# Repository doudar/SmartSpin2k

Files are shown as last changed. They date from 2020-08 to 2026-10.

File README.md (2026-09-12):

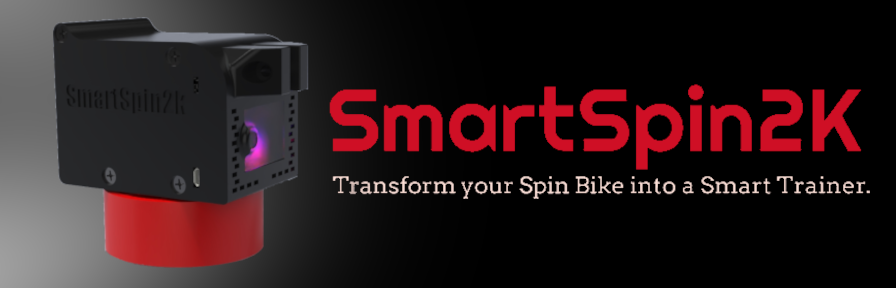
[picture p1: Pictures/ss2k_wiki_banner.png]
ss2k banner


# You can visit us at [Facebook](https://www.facebook.com/groups/716297469953492/)
# Did you know there's a SmartSpin2k companion App?

Find the source code here! -> [SS2kConfigApp](https://github.com/doudar/SS2kConfigApp/tree/develop) 

You can get it from the Apple App Store here:
<div style="display: flex; flex-wrap: wrap;">
<a href="https://apps.apple.com/us/app/smartspin2k-companion-app/id6477836948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" style="display: inline-block;">

</a>
</div>

Or for Android devices: 
<div style="display: flex; flex-wrap: wrap;">
<a href="https://play.google.com/store/apps/details?id=com.smartspin2k.app">

</a>
</div>

# About
SmartSpin2k is a DIY project that allows you to turn any spin bike into a smart trainer. With SmartSpin2k, you can connect your spin bike to Zwift, TrainerRoad, or other popular training apps. This allows you to control your bike's resistance automatically, track your performance, and compete with other riders online.

SmartSpin2k is easy to build and requires only a few simple tools. The [entire build process](https://github.com/doudar/SS2k-Hardware/blob/main/SS2kR3BuildingInstructions.pdf) can be completed in under an hour.

If you are looking for a way to turn your spin bike into a smart trainer, SmartSpin2k is the perfect solution. With its new features and improvements, SmartSpin2k rev 3 is the best version yet.

## Getting Started

To get started with SmartSpin2k, you will need the following:

* A spin bike with a resistance control knob.
* A 3D printer.
* A soldering iron and basic soldering skills.

Once you have these materials, you can follow the [these instructions](https://github.com/doudar/SS2k-Hardware/blob/main/SS2kR3BuildingInstructions.pdf) to build your own SmartSpin2k. If you'd prefer to buy a pre-assembled kit, we have them for sale at [SmartSpin2k.com](https://www.smartspin2k.com/purchase-kits) 

## Features

SmartSpin2k offers a number of features, including:

* Automatic incline resistance control: SmartSpin2k can automatically control your bike's resistance based on the resistance settings in your training app. This allows you to focus on your workout and not worry about adjusting the resistance yourself.
* SmartSpin2k ERG function is a great way to improve your cycling performance. It allows you to train at a consistent power output, which is essential for improving your speed and endurance. ERG stands for "electronic resistance control." It works by automatically adjusting the resistance on your bike based on the power output you set in your training app.
* Online competition: SmartSpin2k can connect to Zwift, TrainerRoad, and many other cycling apps allowing you to compete with other riders online. This is a great way to stay motivated and push yourself to new heights.
* Do you have a spin bike that doesn't output realistic or accurate power numbers? If so, you're not alone. Many spin bikes have inaccurate power meters that can make it difficult to track your progress and train effectively. With SmartSpin2k you can calibrate the power output of your spin bike. 

## Conclusion

SmartSpin2k is a great way to turn any spin bike into a smart trainer. With its new features and improvements, SmartSpin2k Rev 3 is the best version yet. If you are looking for a way to improve your indoor cycling experience, SmartSpin2k is the perfect solution.

### Documentation
Everything you need to know is in the [SS2K Wiki](https://github.com/doudar/SmartSpin2k/wiki)
Hardware files and build assets are in [SS2k-Hardware](https://github.com/doudar/SS2k-Hardware).

## Contributing
1. Install Microsoft Visual Code. https://code.visualstudio.com/
2. Install the **pioarduino IDE** extension (`pioarduino.pioarduino-ide`) recommended by this repository in Visual Studio Code.
3. Install Python https://www.python.org/downloads/
4. Install Pre-commit. https://pre-commit.com `py -m pip install pre-commit`
5. Follow any install warnings to add pre-commit to your path. 
6. Install pre-push git hooks: `pre-commit install --hook-type pre-push`
7. Open this project in the pioarduino IDE.

For command-line builds, use a Python virtual environment and run `python -m pip install -r requirements-ci.txt` from the repository root to install the same pinned pioarduino Core used by CI. CI uses Python 3.11. If that environment already has the upstream `platformio` package installed, uninstall it before installing pioarduino; the two packages share Python modules and command names.

pioarduino still uses `platformio.ini`, the `.platformio` tool directory, and the `pio` / `platformio` commands. Build with `pio run -e release` (classic ESP32) or `pio run -e S3release` (ESP32-S3), and run native tests with `pio test -e native`. See [AGENTS.md](AGENTS.md) for build and validation details.

## Important announcement for existing users
If you experience an issue after upgrading firmware, please follow these instructions in the Wiki. Flashing instructions are available [HERE.](https://github.com/doudar/SmartSpin2k/wiki/Loading-Software)

## Licensing
The hardware designs are licensed under the [CERN Open Hardware License Version 2 - Permissive license](https://github.com/doudar/SS2k-Hardware/blob/main/Hardware/LICENSE).
The software in this project is licensed under the [GNU GENERAL PUBLIC LICENSE Version 2, June 1991 license](LICENSE).

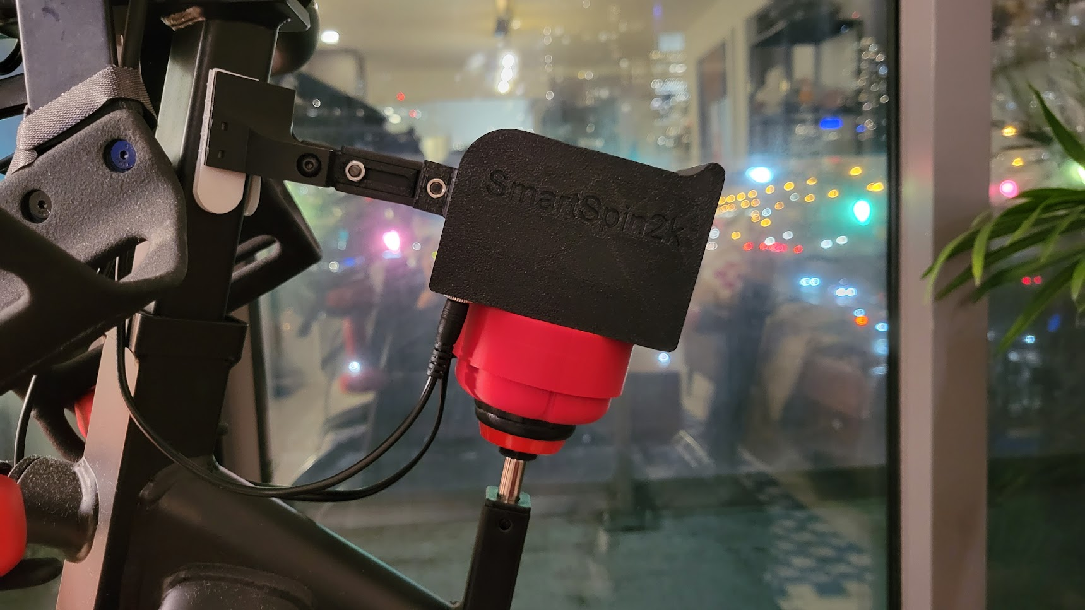
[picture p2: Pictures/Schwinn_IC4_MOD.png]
Hardware 2.0
 

[_^^@eMadman's IC4 model_](https://github.com/doudar/SS2k-Hardware/tree/main/Hardware/V2%20-%20Through%20Hole/Direct%20Mount)

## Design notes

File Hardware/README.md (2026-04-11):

# SmartSpin2k Hardware
V3 is the brand spanking new version where we've gone to a more rigid mount and designed a completly custom PCB with SMT components which can be manufactured using automated techniques. The newest PCB sports a uart->serial driver to allow direct communication with Peloton bikes. 

V2 prints easier, is smaller and uses less hardware. It has a much better gear ratio than V1 and supports a carrier board PCB onto which the devkits mount for easy wiring/soldering.  A rigid mount referred to as Direct Mount is available for stable mounting.

V1 is the oldest printable version. It's slightly more sophisticated than duct tape and cardboard. The common assets do not work with this version, the V1 folder includes knob cups and adaptors specific to V1. You'll probably only use this directory if you need to print replacement parts for a V1.

Hardware is available in two primary versions.  V2 - The Through-Hole soldered version, can easily be DIY'ed by anyone with basic soldering and electronics experience.  V3 - Integrated PCB is new and uses a manufactured PCB with a serial interface specifically designed for integration with Peloton bikes.  

There's additional information in each folder to help you determine what parts might work best for you. 

# Directories
## [V2 - Through-Hole Soldered](https://github.com/doudar/SS2k-Hardware/tree/main/Hardware/V2%20-%20Through%20Hole)
Available in many case versions.  The direct mount mod is the recommended solution for new builders and DIYers.  It is supported on various bikes and is easily adapted to other form factors.  

## [V3 - Integrated PCB](https://github.com/doudar/SS2k-Hardware/tree/main/Hardware/V3%20-%20Integrated%20PCB)
Use with the SMT manufaactured PCB and for compatibility with Peloton bikes.

## [Common Assets](https://github.com/doudar/SS2k-Hardware/tree/main/Hardware/Common%20Assets)
### [Arm](https://github.com/doudar/SS2k-Hardware/tree/main/Hardware/Common%20Assets/Arm)
The Arm is used to connect the SmartSpin2k to the bike mount.  See Readme for sizing and fitment information.

Required for V3 and V2 Direct Mount.

### [Bike Mount](https://github.com/doudar/SS2k-Hardware/tree/main/Hardware/Common%20Assets/Bike%20Mount)
Attaches to the head tube of your bike and provides an attachment point for the arm.

Required for V3 and V2 Direct Mount

### [Gears](https://github.com/doudar/SS2k-Hardware/tree/main/Hardware/Common%20Assets/Gears)
Internal drive gears for the SmartSpin2k.  11:40t gearing.

Required for all V2 and V3 variations

### [Inserts](https://github.com/doudar/SS2k-Hardware/tree/main/Hardware/Common%20Assets/Inserts)
Choose the appropriate insert for your bike.  There are some generic knob designs that apply to several no-name models.  Browse the directory - your bike may already be covered.

Required for all V2 and V3 variations

### [KnobCup](https://github.com/doudar/SS2k-Hardware/tree/main/Hardware/Common%20Assets/KnobCups)
Knob Cup retains the insert and connects to the internal gearbox of the SmartSpin2k

Required for all V2 and V3 variations

### [Shifters](https://github.com/doudar/SS2k-Hardware/tree/main/Hardware/Common%20Assets/Shifters)
You'll want shifters to do sim rides with.  Print this in TPU.

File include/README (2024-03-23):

SmartSpin2k - A buildable software & hardware project that can upgrade a stationary spin bike into a smart bike. 

This software registers an ESP32 as a BLE FTMS device which then uses a stepper motor to turn the resistance knob on a regular spin bike.
BLE code based on examples from https://github.com/nkolban
Copyright 2020 Anthony Doud
This work is licensed under the GNU General Public License v2
Physical prototypes build from plans in the SmartSpin2k repository are licensed under Cern Open Hardware Licence version 2 Permissive

Let the builder beware:  Working SmartSpin2k hardware is experimental and may inadvertently contain serious flaws.
No warranty of any kind is implied or given.  The builder assumes all risks and liabilities with construction and use, be they as minor as a burned out ESP32 or as serious as an injured child.

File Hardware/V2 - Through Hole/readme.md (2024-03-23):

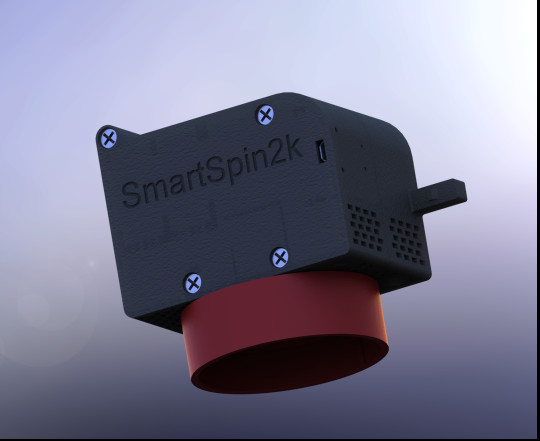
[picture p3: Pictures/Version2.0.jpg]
Hardware 2.0
 
# [Description]
This version of SmartSpin2k is designed with DIY in mind.  The PCB can be hand soldered using readily available components.  

The case for V2 is available in multiple versions that are suitable for various needs.  The direct mount design is the currently recommended case design.

# [PCB]
This directory contains the gerber files necessary to source your own PCB

# [Case Options]
## [Direct Mount (Recommended)]
- Recommended due to additional stability provided on spherical knobs
- Requires some additional parts and components compared to the Universal Mount.  Direct mounts are available for a [variety of bikes](/Hardware/Common%20Assets/Bike%20Mount/)
- Long case is suitable for bikes with a minimum of 115mm of space between the center of the knob and the head tube such as the Bowflex C6, Peloton Bike, and Echelon Connect Sport.  The shortest arm tested by the dev team is suitable for bikes with 130-150mm of clearance
- Short Case is suitable for bikes with minimum clearance of approximately 81mm - such as the Bowflex C7.  

## [Universal Mount]
- Suitable for use across numerous bikes or simply if a direct mount solution is not required in your situation.
- Minimum clearance of 49mm between the center of knob and the rear of the head tube (side closest to the cyclist)  is required

## [Ultra Short Mod]
- This is a version of Case V2 that's been shortened to allow use on bikes with less than 49mm head tube spacing. 

# [Soldering Jig]
- This tool is useful for aligning all the through-hole components for the PCB in order to make soldering easier.  
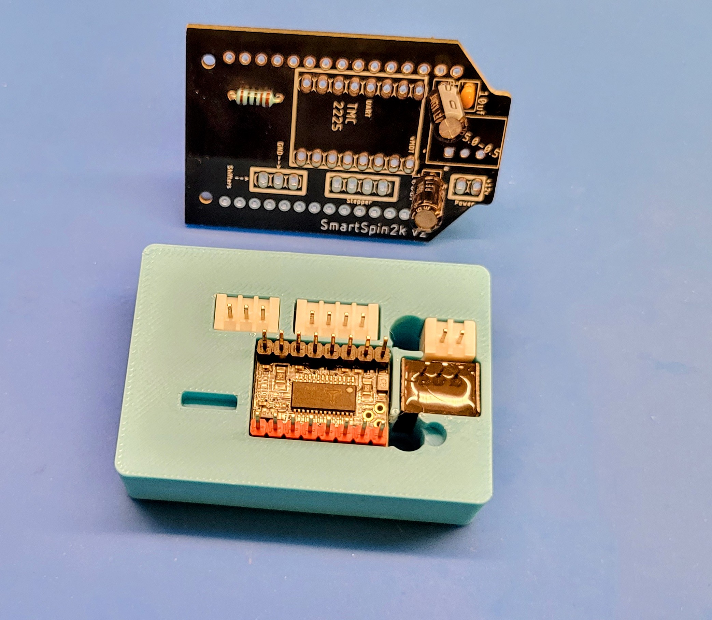
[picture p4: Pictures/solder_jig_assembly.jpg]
Solder Jig


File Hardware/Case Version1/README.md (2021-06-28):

Version 1 of the case. 

Everything here is well tested and works with both the PCB and non PCB builds of SS2K. 

You'll need one print each from the Cases, Covers, Mounts and Stepper Crossbars folders. In addition, you'll need the 11T and 31T gears from the gears folder.

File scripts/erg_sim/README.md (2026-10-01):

# ERG rider/bike simulator

Runs the actual SmartSpin2k ERG controller against a Python bike, with simulated
time driving **all** controller timestamps, motor travel, cadence changes, power
filtering, transport delay, and sensor reports. No device connection is needed.

## Run the supplied workout

### Run with native tests in VS Code

In the **pioarduino** extension's Project Tasks, choose the **native** environment's
**Test** task (`pio test -e native`). The native environment in `platformio.ini`
contains just this hook:

```ini
extra_scripts = post:scripts/erg_sim/native_hook.py
```

After a successful native build, the hook runs the Python simulator checks,
including the complete Random_Attacks workout at FTP 305 W. This also runs when
the binary is already up to date. A simulator failure fails the build/test command;
if it succeeds, the normal native Test action proceeds to the C++ Unity tests.
The hook prints the output folder, `test/output/erg_regression/`; open `response.png`,
`power_table.png`, and `report.md` there in VS Code's Explorer. It uses accelerated
time and requires no bike. Clean/IDE indexing do not run it. `pio test --without-building`
bypasses build hooks. Firmware builds are unaffected. pioarduino retains the `pio`
command and `.platformio` directory names.

This is a local hook: it skips GitHub Actions and requires no workflow changes.
Generic Python test discovery skips the optional simulator suite when its
dependencies are absent; the local native hook instead fails with setup guidance.

Install the dependencies once in **the same Python environment as pioarduino**.
For the default Windows IDE installation, from PowerShell at the repository root:

```powershell
& "$env:USERPROFILE\.platformio\penv\Scripts\python.exe" -m pip install -r scripts/erg_sim/requirements.txt
```

`g++` must also be on VS Code's PATH (restart VS Code after changing PATH). A
missing dependency fails the native build with setup instructions.

### Run directly

Python 3.11+ and `g++` on PATH are required. From the repository root:

```sh
python -m pip install -r scripts/erg_sim/requirements.txt
python -m scripts.erg_sim run --ftp 305
python -B -m unittest discover -s test -p test_erg_simulator.py
```

The default is the supplied `workouts/Random_Attacks.zwo`, FTP **305 W**, seed 27,
the fixed interval cadence plan beside the workout, and the fitted bike from
`profiles/ride_20260927.json`. The whole 4,525-second workout (75:25) runs
in roughly 8 seconds on the development machine, plus compilation/plotting.

```sh
# Run against wall time; 20 means twenty simulated seconds per real second.
python -m scripts.erg_sim run --speed 1
python -m scripts.erg_sim run --speed 20

# Tune controller sensitivity or stress the assumed lag; use separate outputs.
python -m scripts.erg_sim run --sensitivity 3 --output test/output/erg_sensitivity3
python -m scripts.erg_sim run --lag-scale 2 --seed 28 --output test/output/erg_doublelag

# Optional original stochastic rider for less controlled stress tests.
python -m scripts.erg_sim run --rider-mode stochastic --cadence 90 --variation 4
```

`--speed 0` runs as fast as possible. Pacing changes only wall time, never physics
or firmware time. The default IO interval is 20 ms; `--tick-ms` can divide 1,000
between 1 and 100 ms. Both feedback and controller clocks keep running during
held sensor reports. Repeated equal watts still constitute fresh reports.

The runner rebuilds its native executable on every invocation so edits to
`src/ERG_Mode.cpp`, its settings/helpers, power-table learning, or motor dispatch
are actually tested. It does not build ESP32 firmware or alter controller code.

## Output and grading

CLI output goes to `test/output/erg_sim/`. The unittest always runs the complete
ZWO and writes `test/output/erg_regression/`:

- `response.png` / `response.svg`: dark workout chart with FTP-zone segment
  fills, cyan power, green cadence, dashed cadence callouts, separate W/RPM axes,
  and summary scores.
- `power_table.png` / `power_table.svg`: power versus motor-position curves,
  colored by cadence row, with table growth underneath. Dots show stored entries;
  lines join each row's entries without extrapolating outside its learned range.
  Missing entries remain missing in the exported data.
- `learned.ptab`: final controller RAM table exported in the firmware's binary
  format: LE int32 version/quality, one-byte homed flag, row-major int16 position
  and int8 reading weight. Positions retain `TABLE_DIVISOR` scaling. This simulator
  has no FTMS calibration trailer. The physical table comes from production
  learning, not from the simulator's known resistance curve. This exports the
  final snapshot even though LittleFS persistence is stubbed.
- `power_table.json` / `power_table.csv`: table dimensions, coordinates and raw
  entries, including empty cells. Reading weight 1 is inferred/low confidence;
  2+ is a supported entry. The graph is decoded from `learned.ptab`.
- `cadence_plan.json` / `cadence.csv`: resolved interval callouts and actual
  cadence. The plan fingerprint is included in the score metadata.
- `diagnostics.png`: power/target, signed error, and cadence in separate panels.
- `report.md` and `score.json`: quantitative grades and execution metadata.
- `trace.csv`: sensor-report samples, requested/effective target, physical and
  commanded positions, learned table cells, and seek state.
- `firmware.log`: real controller and learning diagnostics.

Grades include maximum absolute error, separate overshoot/undershoot, mean
absolute error, RMS error, bias, time-weighted 95th/99th percentiles, and strict
deviations **over 10, 20, 30, 50, and 100 W**. Each threshold reports:

- Number of sensor samples over the threshold (normally one per second).
- Number of distinct contiguous episodes.
- Total duration, percentage of scored time, and longest episode.

The report's headline grades and chart score cards allow **3 seconds to settle at
the start of each interval**, including workout start and ramp starts. Reports
at exactly interval start + 3 seconds count. The allowance follows workout
segment boundaries, so individual ramp watt updates do not restart it. Max,
MAE, percentiles and every threshold column use the same eligible reports.
Held durations stop at the next interval, excluded gaps split episodes, and
percentages use scored time. Coverage and excluded samples/seconds are explicit;
workouts with no eligible reports show unavailable metrics instead of zero error.

A second full-workout section retains every report, including transitions.
`score.json` keeps these unfiltered metrics at the original `score` keys and
adds the headline metrics under `score.after_interval_grace`. Existing regression
limits continue checking the unfiltered score. The power/error curves retain all
samples. This reporting allowance does not change the controller or simulation.

Requested workout watts are the reference even if firmware clamps the target. An additional
steady score covers constant segments after their first 15 seconds. For each
target jump of at least 20 W, the report measures time until power remains within
20 W for five seconds; `null` means it did not settle before the next segment.
Large instantaneous errors at target jumps are expected with delayed feedback.

The regression uses explicit broad budgets (max 300 W, p95 45 W, MAE 18 W and
threshold duration budgets). These detect deterioration; they are **not** a
claim that the current ERG tuning is optimal. Improvements remain passing. Use
multiple seeds and lag scales before selecting new tuning.

## The thin connection

The Python bike receives only **signed emitted motor steps**. The native bridge
receives only **power/cadence reports and normalized opposing motor load**, plus
the simulation clock and the workout's normal target commands. It never receives
the bike's resistance curve, true physical position, or predicted target position.
Additional positions/counters flow out for diagnostics, not control.

The native adapter compiles complete production `ERG_Mode.cpp`, production
`PowerTable::processPowerValue/newEntry`, `PowerBuffer`, `PTHelpers`, travel-limit
logic, `SS2K::moveStepper`, and `_findEndStop`/StallGuard baseline logic. Only the
peripherals, persistence, network services, and pulse generation are substituted.
Pulse generation uses 3,000 steps/s² acceleration, configured speed, and a 1 ms
integrator. The motor counter counts pulses even at a physical endstop, so the
firmware must detect load rather than read a hidden position sensor.

The standard workout starts homed with assumed bounds 0–24,482 steps and an empty
power table. Production learning runs throughout. Separate endstop tests execute
the production search in both directions; this is not a test of full `goHome`,
thermal protection, FTMS calibration, BLE delivery, or ESP32 scheduling.
The SG adapter maps dimensionless load to a synthetic SG result; it is not a
calibrated torque-in-Nm or TMC electrical model. Filesystem writes are stubbed.

The effective bike model is:

1. Motor pulses move the physical resistance position, with optional backlash
   and physical stops.
2. A monotonic position curve gives watts at 80 RPM; cadence scales it by a fitted
   exponent (1.761 for this ride). Workout target watts never enter this equation.
3. A first-order response (0.775 s) and transport delay (1.117 s) represent the
   combined bike/power-estimator lag. Reports arrive at 1 Hz.
4. Correlated stationary variation uses an 8.10 W robust scale and 1.51 s
   correlation time estimated from the training portion. It includes model error
   and rider effects; it is not an isolated power-meter noise measurement.

## Repeatable cadence scenario

The default `planned` rider uses `workouts/Random_Attacks.cadence.json`. All 40
expanded intervals have explicit cadence callouts. The original 22 intervals retain
their powers, durations, and callouts; two blocks add 810 seconds of small steps:

- Warmup gradually builds from 60 to 90 RPM.
- Three fast-pedaling drills target 110 RPM, with recovery callouts around 85–95 RPM.
- Tempo/recovery callouts are around 80–90 RPM; attacks target 95–105 RPM.
- Building intervals increase cadence gradually, usually by 5–10 RPM over several
  minutes. Cooldown falls from 85 to 60 RPM.
- Within a constant callout, smooth drift is only 2.4 RPM peak to peak over two
  minutes. Sag and gradual callout changes are added separately.
- Intervals with nonzero `sag_rpm` begin sagging after 45 seconds, lose the configured
  RPM over 45 seconds, then regain the target over 10 seconds. The current plan
  includes values up to 10 RPM; validation accepts 0–30 RPM. A 35-second hold follows
  before the next sag. These are explicit scenario assumptions, not new fitted
  physiological measurements.
- After the first hard attack, nine 45-second holds use a 200 W base at 90 RPM:
  200, 210, 200, 230, 200, 220, 200, 240, 200 W at FTP 305.
- Before cooldown, nine 45-second holds use a 300 W base at 85 RPM:
  300, 260, 300, 280, 300, 270, 300, 290, 300 W at FTP 305.
- These add sixteen transitions: four each of magnitude 10, 20, 30, and 40 W,
  including both directions. Cadence callouts stay constant within each block,
  with the existing smooth drift and no added sag, so cadence changes do not mask
  the small target changes. ZWO powers scale with FTP; the stated watt differences
  apply at FTP 305. Each block begins with a separate 45-second baseline hold.

The small-step expansion changes the scenario baseline. Compare controller
settings on the same expanded workout and cadence fingerprint; its lower overall
MAE cannot be treated as an improvement over the shorter original workout.
The standard transition grade uses a 20 W minimum jump and a +/-20 W window,
so it does not score the 10 W steps. For small-step tuning, also inspect first-ten-
second MAE and time within +/-10 W for five consecutive reports, including all
sixteen added steps. Keep the existing overall grading limits unchanged.

The September 28 independent ride supported retaining the current delayed power
response model. Its roughly one-second status logs do not expose fresh-sample
timestamps well enough to distinguish new equal readings from held readings or
identify transport jitter separately from power-estimator lag. No new delay,
dropout, backlash, or noise parameters were fitted from that ride. The observed
app reconnect/SIM-mode switch is outside the bike physics model. Use the existing
`--lag-scale` and `--seed` options for robustness comparisons.

Cadence transitions begin when the interval changes and are limited to 1.5 RPM/s
up and 2 RPM/s down, with a smooth arrival. Every callout, drift, and sag depends
only on workout time. **Actual ERG response cannot change this cadence trace**,
so controller comparisons receive identical rider inputs. Seeds still control
the bike's stationary power variation. The regression verifies cadence invariance
across ERG sensitivities and wall-clock speed multipliers.

Edit the sidecar to change callouts; its canonical fingerprint is saved with each
run. A newline-normalized workout hash and segment-duration checks prevent
silently applying these callouts to a different workout. Compare scores only
under matching cadence plans, FTP, bike parameters and seeds. Switching from the
old stochastic rider to this plan establishes a **new scenario baseline**, not
evidence that firmware improved.

Other workouts honor structured cadence recommendations, otherwise a modest
intensity-based cadence schedule is generated. Descriptive text is not executed.
`--rider-mode stochastic` retains the original fitted cadence distribution
(89 RPM median, 7.94 RPM variation), seeded wander, fatigue and load-driven droop.
`--cadence` and `--variation` apply only to that stochastic mode. Reference
validation continues using recorded cadence rather than either synthetic rider.

## Reference fitting and reproduction

```sh
python -m scripts.erg_sim fit --log "ride-log.txt" --fit "activity.fit"
python -m scripts.erg_sim validate
```

The importer reads status and FTMS targets from the supplied log and decodes FIT
records with `fitdecode`. It aligns the clocks using shared power/cadence. Both
files in this recording are approximately **1 Hz**: 3,899 log samples and 3,955
FIT samples. Alignment power correlation is 0.997. The committed derived CSV
contains relative seconds, power, cadence, positions and targets only; it excludes
GPS, HR, identity, and wall-clock timestamps. Original file hashes are in the
profile. The original FIT/log stay outside tracked source.

Fit parameters use only the first 65% chronologically; the last 35% remains
held out. The effective power response is fitted without using workout targets.
The held-out mean absolute prediction error is **11.21 W**, p95 **31.28 W**, RMS
**15.95 W**. An independently fitted zero-lag model has RMS **23.31 W**. `fit.png`
overlays observed and predicted power with the training boundary marked.

`validate` additionally closes the loop on the first uninterrupted recorded ERG
section (about 33.6 minutes), feeding its recorded cadence and reconstructed
targets into the simulator. All power is then generated by the bike, and all
motor decisions come from current production C++. `validation.json` scores
power reproduction and position difference; `comparison.png` overlays both.
This tests a different claim from replaying recorded positions through the plant.

The original firmware commit, saved power table, and complete settings snapshot
are unavailable, so exact historical commands cannot be guaranteed. One ride is
also insufficient to uniquely identify sensor delay versus flywheel dynamics,
backlash, temperature effects, or arbitrary rider behavior. The model's measured
training envelope is about 6,292–18,881 steps and 56–114 RPM; behavior beyond it
is extrapolation. An independent ride is the next useful validation, rather than
adjusting the model until the entire supplied recording appears perfect.

Supported inputs are FTP-relative `.zwo` blocks (`Warmup`, `Cooldown`, `Ramp`,
`SteadyState`, `IntervalsT`), absolute-watt `.erg` time/power points, or JSON:

```json
{"segments": [
  {"duration_s": 60, "watts": 155, "cadence_rpm": 90},
  {"duration_s": 30, "watts": 335},
  {"duration_s": 60, "watts": 170, "end_watts": 100}
]}
```

ZWO powers are converted to the nearest integer watt. ERG timestamps are minutes
and adjacent points interpolate linearly; duplicate timestamps encode steps.
Unsupported blocks such as free ride fail explicitly rather than inventing an
ERG target. The supplied workout is retained unchanged with its original author
metadata.

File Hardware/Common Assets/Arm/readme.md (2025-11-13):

This directory contains the arm you will use to connect the SmartSpin2k to the Bike Mount from the other folder. You can measure from the back of the head tube to the center of the knob and subtract 65. That will give you an approximation of the arm length you need. The table below will help you make your selection in determining which length arm is appropriate for your bike. In addition, you may use the customizer in Thingaverse to make any length arm that you wish. 
https://www.thingiverse.com/thing:5732525

Manufacturer|Model|Year|Arm Length (range)
----------: |:---:|:---:|:------:
BH Fitness||Any|50
Body Bike|Body Bike|Any|50 (Steep angle)
BodyCraft|MAG|Any|35
Bowflex|C6|Any|65
Bowflex|C7|Any|45
Bowflex|C6|Any|85
Bowflex|IC Bike SE|Any|100
Bowflex|Velocore|150
Dmasun|Any|Any|55
Echelon|Connect Sport|Any| 105
HMC|HMC|Any|60mm
JLL|IC400|Any|35-45
Joroto|X2|Any|20
LeMond|RevMaster|Any|75
Life Fitness|ICG 8|Any|35-60
Merach|Any|Any|70
Peloton|Bike|Any|75 (90 for slammed bars)
PooBoo|?|Any|60-80
PooBoo|616M2|Any|50
Schwinn|IC4|Any|85
Schwinn|AC|Any|20-40 (mount needs to go above SS2k)
Spinning|L7|Any|20-40 (mount needs to go above SS2k)
SOLE|SB700|ANY|20-40ra
Soulcycle|Equinox|Any|155-165
Stryde|Any|Any|110-120
Sunny|B1805|Any|35
Vortec|Vortec|Any|20
York|SB300|Any|20-40
Yosuda|Pro|any|20-40 (mount needs to go above SS2k)
Yosuda|L-007C|Any|20-40 (mount needs to go above SS2k)
Yesoul|S3|any| 140 (145-150 may be better)

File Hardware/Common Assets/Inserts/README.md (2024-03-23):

These are the parts that adapt your knob to the SmartSpin2k. 

You'll see two of most of these because as we make them we've designed two slightly different sizes to accommodate 

Design Reference Photos are the images and dimensions we've used along the way to create various inserts. 
Most of the new knobs have been designed in Solidworks because that's currently  @doudar 's favorite CAD program. Feel free to recreate them in your favorite CAD program and we will happily PR them into a subfolder for that program.

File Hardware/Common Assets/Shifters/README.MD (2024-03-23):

# 2-in-1 strap
This design is intended for printing with TPU.  You will need a hot glue gun for assembly.

Fusion 360 exports and generic STEP files are both provided

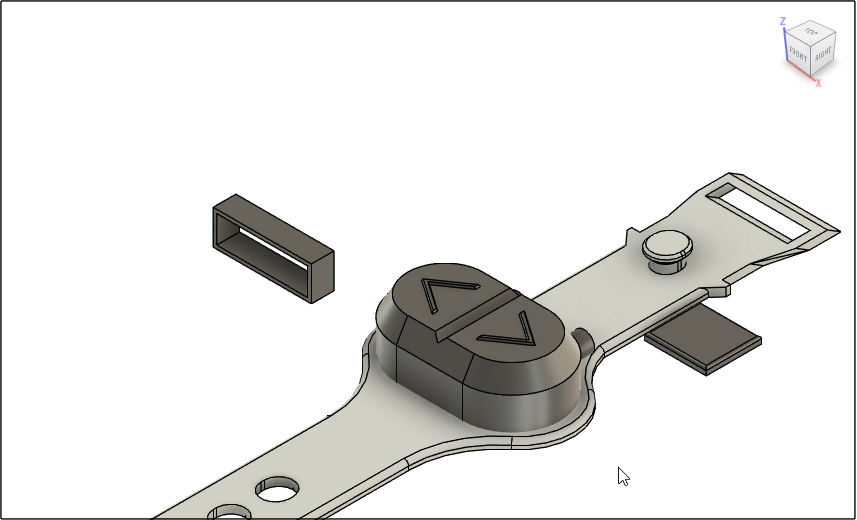
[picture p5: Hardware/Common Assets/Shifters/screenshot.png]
render of remote


## Assembly Instructions
- [See Shifter Assembly video linked in Wiki](https://github.com/doudar/SmartSpin2k/wiki/Building-How-To)

## Setup
- In case you need to flip the orientation of the shifter, you can easily do so in the SmartSpin2k User Interface.  Navigate to [http://SmartSpin2k.local/](http://SmartSpin2k.local).  Here, you can toggle the Shifter Direction button until the device shifts in the right direction and save your settings.  You can verify your settings in the [Web Shifter](http://smartspin2k.local/shift.html)

## BOM
- Momentary microswitches
- 1 RCA to 3.5mm audio cable
See [Recommended Hardware in Wiki](https://github.com/doudar/SmartSpin2k/wiki/Recommended-Hardware) for examples and sourcing information

## Printing instructions
The bridging layers on this print are tricky to get right with TPU.  It is important to minimize gaps in the bridging layers and ensure it is well sealed against sweat and water.  The instructions listed here have worked well in Superslicer or Prusaslicer. With good cooling and a slow print speed, this print is very achievable. 

If you are unsure, print test_housing.stl - this will print much more quickly than the full strap and allow you to dial in the print using less material and time.

- Cooling fan at 75% (this is different for every printer and duct - I'm using a single 5015 fan)
- 0.2mm layer height with 0.4mm nozzle
- 3 perimeters
- Supports disabled
- 20% infill
- Monotonic top, solid, and bottom infills
- Infill Angle - 90 Degrees (You want the lines following the length of the strap)
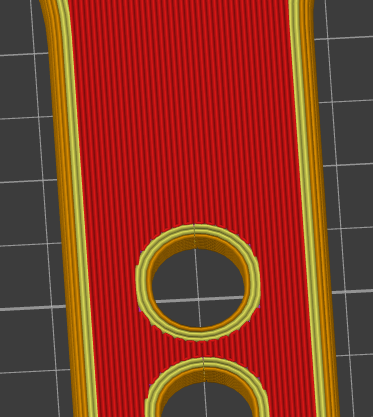
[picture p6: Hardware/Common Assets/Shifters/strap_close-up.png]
close up of strap
- 
- Add a height range modifier on the strap from 8.85-13.70mm with the following settings.  The combination of ironing and concentric infill help ensure a watertight finish.
-- Solid Infill pattern: Ironing
-- Top Infill Pattern: Concentric
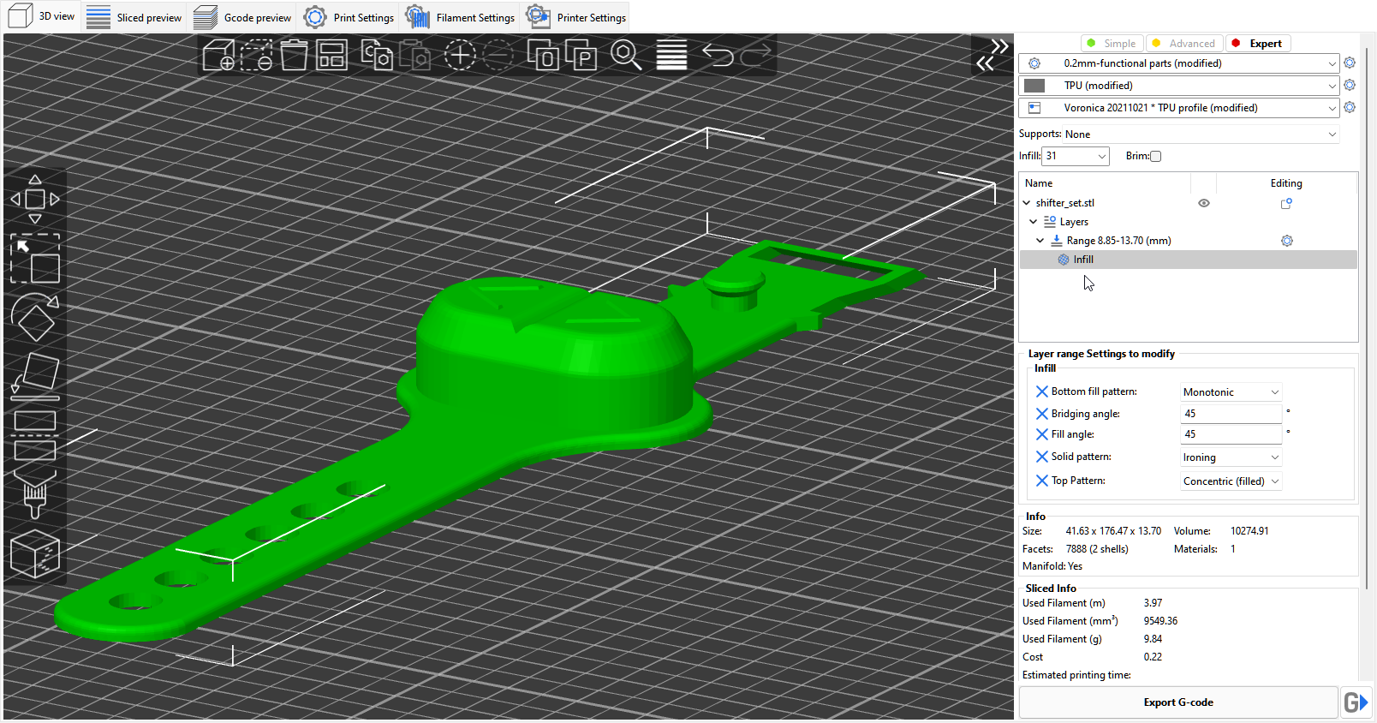
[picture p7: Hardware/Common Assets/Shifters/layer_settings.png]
layer settings screenshot
-- 

## [Test Print]
- test_housing.stl

## [Full Set]
- shifter_set.stl

## [Strap]
- strap.stl

## [Plug]
- plug.stl - x2

## [Retainer]
- retainer.stl

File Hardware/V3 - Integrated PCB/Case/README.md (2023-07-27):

Hardware for use with the R3 PCB. 

# Revision 3

Introduces the newest PCB with a serial interface specifically designed for integration with Peloton bikes and provides a path for DIY'ers to order a board and cable kit that doesn't require any soldering skills. It's "print", "plug" and "play".  

The case is suitable for bikes with a minimum of 80mm of space between the center of the knob and the head tube.  It has been tested on the Peloton Bike and clearance for fit is confirmed on Bowflex C6, Echelon Connect Sport, and Peloton Bike.

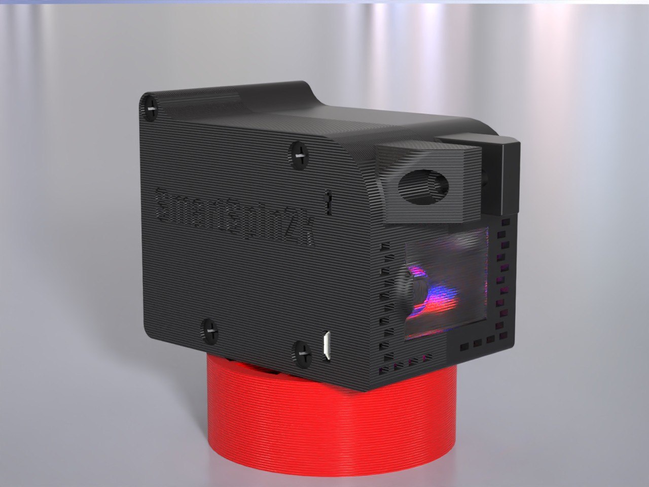
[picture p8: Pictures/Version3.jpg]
Hardware 3.0


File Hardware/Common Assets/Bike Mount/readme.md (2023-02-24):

This directory contains the specific part you'll nee to connect SmartSpin2k to the head tube on your bike. 

If you cannot find one that exactly matches your bike, we've designed a mount in Openscad that you may be able to customize in Thingaverse to make your own. 
https://www.thingiverse.com/thing:5738735

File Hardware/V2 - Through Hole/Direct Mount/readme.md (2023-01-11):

# Bowflex C6 / Schwinn IC4 mod
This mods the version2 case of SmartSpin2k to have a dedicated mount for a Schinn IC4 / Bowflex C6.  This should work with other bikes with minimal modification.  Bike mount.stl is intended for semi-permanent installation with zip ties or VHB tape.  This allows 1-handed installation and removal while offering a lot more rigidity than the original, highly portable design.

Fusion 360 exports and generic STEP files are both provided




## Revisions from standard version 2 case:
- Designed for direct mounting to a bike's head tube - Schwinn IC4 and Echelon Connect Sport mounts currently available.
- Replace wood screws with M3 threaded inserts to accept m3 screws. Source from [Aliexpress](https://www.aliexpress.com/item/4000232858343.html?spm=a2g0s.9042311.0.0.21164c4dGhWHhY): M3 x 5 x 4 heat set inserts. (5mm diameter).
- Sturdy yet easy to install and remove between rides.

## BOM
- In addition to the electronics specced for the version 2 case, you will need:
- M3 x 5 x 4 heat set inserts. (5mm diameter).  Source from [Aliexpress](https://www.aliexpress.com/item/4000232858343.html?spm=a2g0s.9042311.0.0.21164c4dGhWHhY).  [Instructions for installation here](https://www.youtube.com/watch?v=cyof7fYFcuQ)
- 4xM3 screws - I think M3x8 or M3x10 should work. As long as it's long enough to go into the threaded inserts, the length doesn't matter.  There's plenty of clearance if it's too long
- 1 pc M5x12mm for the the arm
- 2pc M5x30mm - 1 for the bike mount and another for the case
- 3pc M5 nuts

For the bike mount, you have two options: VHB tape or something similar OR if you want to protect the paint and avoid adhesives, you can use the velcro strap and rubber sticker approach:

- 1pc 1/2" wide velcro cable tie - 8" works for Schwinn and Echelon.  [This or something similar.](https://www.amazon.ca/gp/product/B001E1Y5O6/ref=ppx_yo_dt_b_search_asin_title?ie=UTF8&th=1)  
- 2mm non-slip adhesive backed rubber.  [Something like this](https://www.amazon.ca/gp/product/B00P5VQ7HE)

## Printing instructions
- 4 perimeters
- 40% infill
- 0.2mm layer height
- Supports enabled (from print bed only) for ic4-body-left.stl and ic4-body-right.stl

# From the Mod
## [Case]
- body-left.stl
- body-right.stl

## [Short Case]
- use for bikes with minimal knob clearance like the Bowflex C7
- body-left.stl
- body-right.stl

## [[Bike Mount](/Hardware/Common%20Assets/Bike%20Mount/)]
-Choose the one you need.  IC4 design works with most square profile head tubes.

## [[Arm](../../Common%20Assets/Arm/)]
- _arm hook.stl (mandatory)
- Choose the one you need.  
-- IC4 arm is designed for a center of knob to head tube distance of approx 130-150mm
-- Echelon arm suits a distance of approx  160-180mm

## [Knob cup and insert]
- [Knob Cup](/Hardware/Common%20Assets/KnobCups)
- [Choose the insert for your bike](/Hardware/Common%20Assets/Inserts/)
Mix and match inserts to suit your bike.  

## [[Gears](/Hardware/Common%20Assets/Gears/)]

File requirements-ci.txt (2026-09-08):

# Use pioarduino Core with the pioarduino ESP32 platform and its SCons 4.8.1.
# This package still provides the platformio and pio commands.
pioarduino==6.1.19

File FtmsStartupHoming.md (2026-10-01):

# FTMS startup recovery and position synchronization

## September 21: one shared downward reference (current policy)

The three startup runs in the 11:05 log selected the same gear-8 target, P6426,
but settled at R28–29, R26, and R29. Recovery had accepted R48 approached upward
for the low starts and R55 approached downward for the high start. Those
different references confound interpolation error, sensor settling, and drive
play; the log alone cannot distinguish their contributions.

Full calibration and every startup now share the same R51-to-R50 downward
crossing search. First, bounded stationary-observation moves stage near R58;
then the search approaches from above and brackets the crossing to 80 steps.
Reversed bracket probes back off by five estimated resistance levels (capped
at 6000 steps) before approaching downward again. A reading taken during motion
cannot establish the reference. Each measurement requires a stopped motor,
at least two seconds of dwell, and fresh confirmed feedback. Adjacent 50/51
jitter is accepted only after a downward approach. The 120-second deadline,
no-response travel guards, cancellation, and motor/report failures still apply.

The middle map entry stores that crossing at R50.5. Startup subtracts the saved
crossing coordinate from the newly measured bracket midpoint, rather than
interpolating whichever middle reading it happens to reach. The motor's final
probe position need not equal the bracket midpoint; rebasing accounts for that.
The outer map samples remain stationary observations near R33 and R67 for
ride-time interpolation. Initial calibration and startup use the same code
for the middle reference, including approach and settling.

This is the 32-byte FTM3 trailer. FTM1/FTM2 maps trigger a one-time full
calibration; automatic migration retains saved watts and only replaces the
file after successful calibration. A failed search uses the runtime Unlimited
fallback. Startup now includes a repeatable crossing search even if powered on
at R50, so the old under-20-second/no-motion targets below no longer apply.
The prior implementation and measurements below are historical context.

Native regressions cover calibration followed by boots from R0/R26/R50/R100
with 750 steps of drive play, 1.3/2.5-second sensor delays, and false R50 reports
through motion and the first two stopped seconds. Recovered origins differ from
the calibration frame by at most 80 steps in this model. These cases take
36–53 seconds, excluding BLE connection and the move to the starting gear;
the wider-noise case takes about 85 seconds. These are simulated timings, not
hardware measurements. Mid-search cancellation, missing feedback and motor
command failure stop without producing a recovered origin. Persistence tests
verify FTM2 migration preserves watt entries and leaves the saved file untouched
until successful replacement.

## September 19 log findings

The 09:16 run failed after 49.7 seconds on the no-progress guard at resistance 4.
The 10:52 run crossed that wide level successfully, but failed after 212.9 seconds
while trying to confirm the final 30% map transition. The minimum took 61.3 s,
the maximum roughly 54 s, and the five-reference map phase roughly 98 s.
At the last reference, the stationary sensor jumped from 29 to 31 across a
20-step bracket. Rejecting that imperfect crossing discarded the entire run.

The completed references below are reconstructed bracket midpoints, not
independent physical measurements. Zero was -6836; maximum was approximately
17666, giving 24502 steps of virtual travel.

| Resistance transition | Raw position | Percentage of virtual travel |
| --- | ---: | ---: |
| 41 -> 40 | 2353 | 37.50% |
| 51 -> 50 | 4988 | 48.26% |
| 61 -> 60 | 7508 | 58.54% |
| 71 -> 70 | 10304 | 69.95% |

Their least-squares middle-range slope is 263.73 steps/level. The largest
residual is 98.9 steps, equivalent to 0.375 resistance levels or 0.404% of total
travel. This supports sparse middle-range interpolation for this run. It does
not prove the entire range is linear: the endpoint-derived slope is 245.02
steps/percent, about 7.6% lower, and level 4 is conspicuously wide. The measured
50 transition is 427 steps below the 50% travel position. A single 50% reference
would recover an offset but could not independently establish the middle slope.

The log also shows delayed reports: at stationary position 9491 the reading
changes from 77 to 70 to 68. Shortening every wait would accept stale movement
feedback. Reducing the number of probes removes more time without relying on
those early reports.

## Revised calibration

Full calibration retains the two virtual endpoint searches, then measures near
33, 50, and 67. These are stationary samples, not precisely located transitions.
The search accepts a reading within two levels of its aim and stores the actual
observed resistance and position. Adjacent readings can be averaged into a half
level. Most of the middle is interpolated between these three samples; there is
no scan through every resistance level.

Three observations retain a measured slope on each side of the middle. Compared
with a two-point format, the complete trailer is just four bytes larger; the
middle measurement can expose curvature instead of assuming it away. The FTM2
trailer is 32 bytes: magic/version (4), source/direction fingerprint (4), maximum
(4), three positions (12), three doubled-resistance values (3), reserved byte
(1), and checksum (4). This replaces the five-point, 40-byte FTM1 format.

Target movement shares `ResistanceControl::Controller` with normal resistance
mode. Endpoint approaches use its live incremental targets; map/startup moves
use the measured steps-per-level gain with a 6000-step move limit. Once the
stepper reaches its position target, fresh unchanged resistance for one second
confirms the sample. Monotonic adjacent changes restart confirmation; an actual
back-and-forth across adjacent levels can confirm their midpoint. Persistently
noisy feedback uses the latest two readings at five seconds rather than failing.
Only final endpoint transition probes retain their two-second acquisition guard
for repeatable zero estimation. A
previous confirmed observation is reused between adjacent map searches; do not
wait again before issuing the next movement. Every saved sample is logged with
actual resistance, coordinate, and percentage of travel.

Endpoint searches accept the midpoint of a completed bracket even when the
sensor skips the requested integer. They no longer make an extra final return
move and wait just to confirm that same bracket. Wider analog noise can be
averaged; a changing timestamp alone still does not prove that the sensor
responded to motor travel. Frozen readings, sustained lack of useful response,
missing reports, cancellation, and motor errors retain bounded stopping paths.
The overall endpoint deadline remains 120 seconds as a final travel safeguard.

## Persistence and startup

PTAB watts entries keep their existing version-6 layout. FTM1, missing,
truncated, corrupt, or mismatched metadata triggers a full FTMS calibration.
Legacy migration preserves watts; explicit full calibration retains the existing
watts-reset policy. Metadata-only tables can save immediately. Saves use a
temporary file and rename after all bytes are written. Reset removes both map
and watts. No BLE table-transfer format changes.

With matching metadata, startup samples stationary resistance and interpolates
within the measured support, normally approximately 33–67. Adjacent jitter uses
its averaged resistance instead of forcing another transition hunt. Outside
that middle, bounded fast moves aim toward 50 until feedback enters the map.
Startup aims for under twenty seconds but does not abort responsive feedback
just because it exceeds that target. The 120-second overall safety deadline
and no-response travel guard still bound recovery. Recovery rebases coordinates, clears the ride-time gear offset, and selects the
absolute starting-gear target: eight Shift Amounts above zero for Unlimited, or
the ratio offset of `max(1, gearCount / 3)` for bounded groupsets. Normal motor
control moves directly there after homing restores its safety policy, with the
usual travel clamps; no intermediate return to zero is needed.

## Ride-time correction and the 11:40 log

The next run recovered successfully in about 10.7 seconds, finishing at
R48/P11520. Shifting from gear 8 to 6 moved to P9100 and R38/39. After manual
removal and reseating, R32 persisted from 160.451 to 206.693 seconds while P9100
never changed. This was sufficient stationary evidence to correct the offset.

The old policy was too restrictive: offsets above three local deadbands were
rejected outright, correction was limited to 100 steps per minute, adjacent
38/39 jitter restarted confirmation, and R32 could fall outside the saved sample
support. The log does not include the saved map or rejection diagnostics, so it
cannot identify every gate that fired on this particular device.

The revised policy keeps the same 32-byte FTM2 metadata and needs no new
calibration. Within R30–70, estimates may extend at most five levels past a
sample using its nearest measured slope. Each extrapolated level adds half a
local resistance bin to uncertainty. Startup still requires measured support;
there is no ride-time extrapolation into the unreliable ends.

Correction requires ten seconds of position stable within five steps and at
least nine fresh reports. One adjacent resistance pair is allowed and its
sample-weighted mean is used. Larger changes restart confirmation. For offsets
above three deadbands, require thirty seconds and at least 25 reports instead
of rejecting the discrepancy. Missing/stale feedback, motion, pending movement,
homing, updates, external control, simulation, ERG table seeking, and motor
inhibits disqualify an observation.

When error exceeds the deadband, rebase to the estimated position in one update.
The deadband is one local resistance level plus 40 steps, increased for short
extrapolations. At most one applied correction is allowed per minute. Checks
that find no discrepancy do not consume that interval, and brief driver-lock
interruptions do not continually postpone it. Update position, target, and
relevant ERG/gear offsets together without issuing a motor command.

Power-table collection continues while a position discrepancy awaits
confirmation or cooldown. Only applied corrections
advance `positionEpoch` to prevent mixing pre/post-correction samples. Already
learned entries are not retroactively changed.

A regression follows the logged timing and resistance sequence with a synthetic
map consistent with R48/P11520 and R38.5/P9100. Depending on the actual lower
sample position, it rebases within 10–30 seconds of stationary evidence, without
motor commands or changing gear 6. The real saved PTAB is absent from the log,
so the regression's resulting P7440 is illustrative, not a claimed exact target
for this bike. Periodic `FTMS sync check` logs now expose the guard state.

## Validation

Native tests exercise acceleration, delayed 1 Hz reports, noise, skipped levels,
wide level 4, stale/simulated reports, cancellation, unresponsive sensors,
metadata round trips, and startup/drift guard behavior. The log-shaped model
interpolates stationary observations from this run; it is not a replay of
physical motion or a guarantee of hardware repeatability.

| Synthetic scenario | Time |
| --- | ---: |
| Stationary startup within measured support | Under 5 s, no movement |
| Startup R1/R20/R80/R99 at 100 steps/level | 7 s |
| Startup R1/R99 at 300 steps/level | 12 s |
| Noisy R99 startup at 300 steps/level, 2.5 s report delay | 19 s |
| Three map observations, ideal 100 steps/level | 15 s |
| Three observations, this log's middle curve, 1.3/2.5 s delay | 22/26 s |
| Same curve with additional +/-2 level noise | 34.5 s |
| Minimum with an extra 1200/2400-step level 4 | 81/87 s |

Full first-time calibration remains longer than startup recovery. These search timings exclude BLE connection and the subsequent move to the
starting gear. They are simulations, not measurements on the user's bike.
Integration regressions cover actual persistence and homing orchestration,
failed writes/renames, migration, and correction without physical movement.

## Shared resistance control and September 19 14:50 log

The recorded calibration spans about 175 seconds: 64 seconds finding minimum,
80 finding maximum, and 30 sampling the map. Samples R32/P7484,
R48.5/P11622 and R67/P16161 show a middle interpolation residual of 47 steps.
These measurements support a sparse map but not a raw resistance-percent to
travel-percent identity. The existing three-point, 32-byte format is unchanged.

Exact resistance target equality now holds the current position. The shared
controller adds derivative braking based on fresh resistance reports. Crossings
from more than two levels below to more than two above (or vice versa) add
0.5 seconds to D, capped at 2.5 seconds. D only reduces movement approaching a
target; it never commands motion away from it. A new target or ten seconds of
controller inactivity resets D. A fresh unchanged reading sets velocity to zero;
held reports older than 1.5 seconds stop contributing derivative braking.
Normal resistance moves log changes in D. No persistent metadata is added.

The spindown opcode previously remained selected after success, bypassing local
gearing and allowing the recovered step position to become an incline term.
Successful spindown now returns to simulation with zero incline before selecting
the starting gear. All shipped groupsets are covered by integration regressions.

## September 20 full-calibration motor-enable failure

The 20:24 log recovers from R90 using saved metadata in about six seconds,
then moves to the correct starting-gear position (P6426/R25). A later full
calibration finds minimum after 58 seconds, then reports R1–2 while its counter
moves P1108 to P4143 toward the R90 target and trips the no-response guard.
R90 is the requested anchor, not the resistance reached at failure.

Homing inherited manual enable from cadence unless a thermal inhibit was active.
FastAccelStepper retains its previous automatic-disable countdown when manual
enable is selected; stationary time during a long calibration can expire it.
Normal maintenance continually re-enables outputs while pedaling, but is skipped
during homing. Subsequent manual-mode commands can advance the step counter with
outputs disabled. Homing now always selects automatic enable so each move renews
the timer and re-enables an expired output. Safety interlocks are still restored
on exit. This reproduces the counter-without-physical-motion failure in a test;
the log contains no EN-pin measurement, so confirmation on the bike is needed.

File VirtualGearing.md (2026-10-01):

# Ratio-based virtual gearing

Local simulation/inclination modes use the selected groupset on both ESP32 and
ESP32-S3. There is no weight setting, road-load physics, power-table readiness
check, cadence gate, or timed shift effect. ERG and resistance controls retain
their existing behavior; external motor control and app-owned virtual shifting
retain precedence.

## Unlimited (default)

An empty `gearTeeth` array (`[]`) with `gearPreset: 0` selects Unlimited, the default for new/reset
settings and older configurations without a gear profile. Each shift moves by
`shiftStep`, and the logical shift position can go positive or negative without
a groupset limit. Startup assigns the existing knob position to gear 8 by setting
the stepper coordinate to `8 * shiftStep`, without moving the motor. Homing, when
configured, replaces this provisional coordinate. After successful homing the
starting gear is 8, with a physical target of `8 * shiftStep` above calibrated zero.
FTMS homing moves directly from the recovered position to that target through
normal motor control; it does not assign gear 8 to the search endpoint.
Saved homing bounds alone do not count as a successful home this boot.
Motor travel limits remain active. Ratio-only test profiles are no longer supported;
configurations without a tooth profile or named preset use Unlimited.

```
gearOffset = shifterPosition * shiftStep
```

## Mapping bounded ratios to steps

Let `medianGap` be the median of the positive differences between adjacent sorted
gear ratios. For an even number of gaps, average the two middle gaps.

```
gearOffset = round(shiftStep * (ratio[selectedGear] - ratio[firstGear]) / medianGap)
targetPosition = gearOffset + targetIncline * inclineMultiplier
```

`shiftStep` (Shift Amount in the web UI) is the motor distance for a median-sized
ratio gap. For ratios 1.0, 1.1, 1.3, 1.6 and Shift Amount 1200, the median gap is
0.2; successive moves are 600, 1200, and 1800 steps. Absolute offsets are 0, 600,
1800, and 3600 steps. Computing from the first gear prevents accumulated rounding
drift when shifting repeatedly.

Gear 1 has zero shift offset.
Gear numbers are bounded to 1 through the profile length, independent of hardware
travel. A profile change from 22 to 13 gears clamps gear 22 to gear 13. Mode
changes retain the last local gear for the session. Startup and homing use
`max(1, gearCount / 3)`, rounded down: gear 8 for 24 gears, or gear 4 for 12/13
gears. Startup assigns the existing knob position that gear's ratio offset without
moving the motor. Normal control then applies that gear's ratio offset from calibrated zero
after either FTMS or mechanical homing. This is one third of the gear count,
not one third of total motor travel. Homing clears any prior ride-time drift
offset; later stationary FTMS corrections retain their coordinate-only behavior.
Successful FTMS spindown also clears its procedure opcode to simulation mode and
zeros incline before selecting the gear. Otherwise local ratio gearing is
bypassed and the recovered position can incorrectly become a terrain offset.
Regression cases include Unlimited (8), Road (8), MTB (4), Gravel (4), Mixed
Terrain 1x24 (8), and All-Rounder (8).
Duplicate ratios share an offset and zero gaps do not count toward the
median. An all-identical profile has zero shift offset in every gear.

Ratio differences and the cached median use integers. Offset calculation uses
64-bit intermediates and saturates before conversion to stepper positions. Each
change commands a complete target; FastAccelStepper manages acceleration. Normal
homed/provisional travel limits and hardware guards still apply. Profiles are not
stretched to fill the physical travel; large gaps or steep terrain may hit a
travel limit before the last gear.

Terrain remains additive using the existing incline multiplier. Changing gear
while stopped changes the brake target immediately, as with the original step
shifting. Sensor delay and power-table trust do not affect shifting. Power tables
remain in use for ERG and optional power estimation.

## Configuration and firmware API

The firmware-hosted groupset selector provides:

- Unlimited: fixed Shift Amount spacing, no logical gear bounds (default).
- Standard Road Compact: 50/34T | 11–34T, 24 sorted ratios.
- MTB 1x12 – Wide Range: 32T | 10–52T, 12 ratios.
- Gravel 1x13 – Optimized XPLR: 42T | 10–46T, 13 ratios.
- Mixed Terrain 1x24: built-in 24-gear mixed-terrain ratio table (0.75–5.49),
  starting at gear 8 (1.68).
- All-Rounder: 48/35T | 10–33T, 24 sorted tooth combinations. The cassette
  is 10, 11, 12, 13, 14, 15, 17, 19, 21, 24, 28, 33T.

Tooth-based groupsets store 2–26 unique tooth pairs as `front * 100 + rear`: `5332` means
53x32. Both tooth counts must be 1–99 and the rounded ratio must remain 500–6000
in thousandths. Firmware sorts by that ratio, breaking equal-ratio ties by the
packed pair. Ratios are derived once for the existing motor mapping, so shift
spacing and startup behavior remain unchanged. Equal ratios from different tooth
pairs remain distinct gears with the same motor offset.

Persistence and config/all-settings responses include `gearPreset` and
`gearTeeth`. Preset 0 uses the tooth array (empty means Unlimited); preset 1 selects
the built-in Mixed Terrain 1x24 ratios and stores an empty tooth array. Mixed
Terrain 1x24 has no real tooth combinations; the profile represents a single
24-gear rear axis without inventing teeth. No arbitrary or legacy ratio-array input is
supported. Validation and median calculation finish before publication under a
short critical section. Both bounded formats use the same motor mapping above.

HTTP `/send_settings` accepts `gearTeeth` as a packed-pair JSON array and
`gearPreset` as 0 or 1, and `shiftStep` through its existing field. Submit either
`gearTeeth` or `gearPreset` in one request, not both. A tooth-array write exits
the built-in preset. Invalid profiles return HTTP 400 without
replacing the current profile. Old saved rider weight fields are ignored and
disappear on resave. The experimental rider-weight custom ID 0x33 is retired.

Custom characteristic 0x34 provides metadata/indexed reads and atomic tooth-pair
profile writes; 0x35 selects/reads the named preset. Tooth reads return an error
while Mixed Terrain is selected. See [CustomCharacteristic.md](CustomCharacteristic.md) for byte
formats. To select Unlimited, write `02 34 00`; metadata reads return `80 34 00`,
and indexed reads return an error because there are no stored pairs.
A full 26-gear write requires MTU 58; metadata and indexed reads fit MTU 23.
Save BLE/DirCon changes with command `02 18`; web settings save automatically.

Incoming FTMS simulation commands still require seven bytes; inclination commands
require three bytes. Local movement uses the received grade and ignores wind/drag
coefficients. Forwarding to an FTMS bike uses the current combined gear/terrain
target translated to grade, retaining the other received simulation fields.

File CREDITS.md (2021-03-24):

# Credits
Thanks to the authors of these libraries :
- [NimBLE-Arduino](https://github.com/h2zero/NimBLE-Arduino)
- [ArduinoJson](https://arduinojson.org)
- [TMCStepper](https://github.com/teemuatlut/TMCStepper)
- [Universal-Arduino-Telegram-Bot](https://github.com/witnessmenow/Universal-Arduino-Telegram-Bot)

Thanks to Neil Kolban for his [BLE code examples](https://github.com/nkolban).

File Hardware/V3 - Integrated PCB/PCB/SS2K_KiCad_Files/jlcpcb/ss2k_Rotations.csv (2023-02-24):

Footprint pattern | Correction
^(.*?_|V)?QFN-(16|20|24|28|40)(-|_|$) | 270
^BatteryHolder_Keystone_1060_1x2032 | -180
^Bosch_LGA-8_2x2.5mm_P0.65mm_ClockwisePinNumbering | 90
^CP_EIA- | 180
^CP_Elec_10x10 | 180
^CP_Elec_6.3x7.7 | 180
^CP_Elec_8x10.5 | 180
^CP_Elec_8x5.4 | 180
^CP_Elec_8x6.7 | 180
^DFN- | 270
^Diodes_PowerDI3333-8 | 270
^ESP32-W | 270
^HTSSOP- | 270
^HTSSOP-28-1EP_4.4x9.7mm* | 270
^JST_GH_SM | 180
^JST_PH_S | 180
^LED_WS2812B | 180
^LQFP- | 270
^MAX3232IPWR | 270
^PUIAudio_SMT_0825_S_4_R* | 270
^PowerPAK_SO-8_Single | 270
^Quectel_L80-R | 270
^RP2040-QFN-56 | 270
^R_Array_Concave_ | 90
^R_Array_Convex_ | 90
^Relay_DPDT_Omron_G6K-2F-Y | 270
^SO-14 | -90
^SOIC- | 270
^SOIC127P798X216-8N | -90
^SOP-(?!18_) | 270
^SOP-18_ | 0
^SOP-4_ | 0
^SOT-223 | 180
^SOT-23 | 180
^SOT-353 | 180
^SOT-363 | 180
^SOT-89 | 180
^SSOP- | 270
^SW_DIP_SPSTx01_Slide_Copal_CHS-01B_W7.62mm_P1.27mm | -180
^SW_SPDT_CK\-JS102011SAQN | 270
^SW_SPST_B3 | 90
^TDSON-8-1 | 270
^TO-277 | 90
^TQFP- | 270
^TSOP-6 | 270
^TSOT-23 | 180
^TSSOP- | 270
^Transformer_Ethernet_Pulse_HX0068ANL | 270
^UDFN-10 | 270
^USB_C_Receptacle_HRO_TYPE-C-31-M-12* | 180
^USB_C_Receptacle_XKB_U262-16XN-4BVC11 | 180
^USON-10 | 270
^VSON-8_ | 270
^VSSOP-10_ | 270
^VSSOP-8_ | 180
^VSSOP-8_3.0x3.0mm_P0.65mm | 270

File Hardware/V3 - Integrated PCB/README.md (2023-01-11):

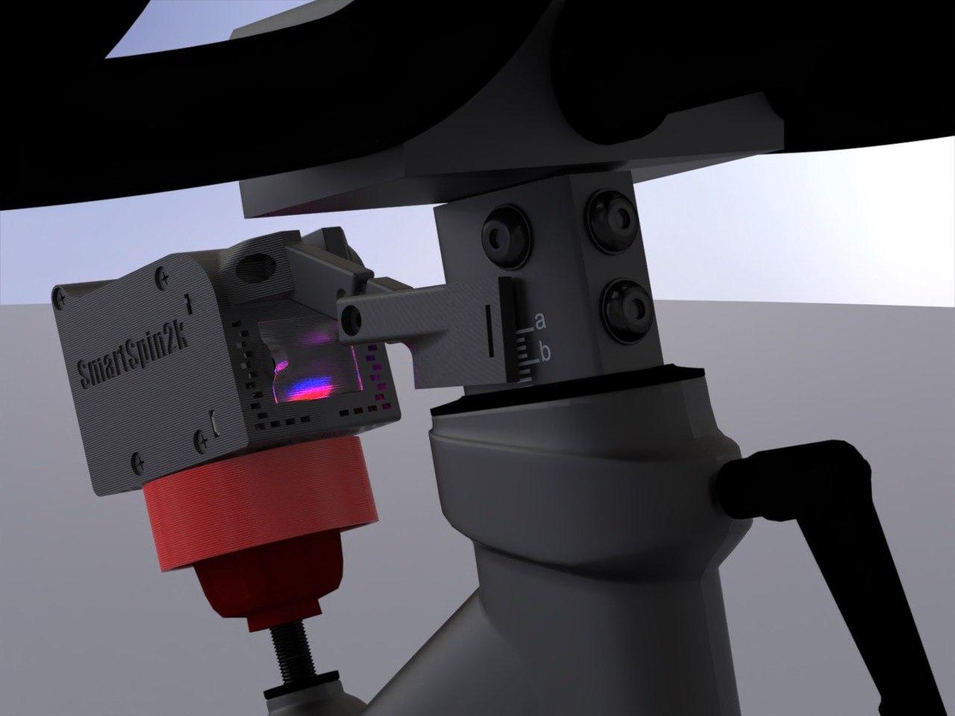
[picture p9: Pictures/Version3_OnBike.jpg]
Hardware 3.0


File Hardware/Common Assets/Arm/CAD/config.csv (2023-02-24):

exported_filename | armLength
armWithHook20 | 20
armWithHook25 | 25
armWithHook30 | 30
armWithHook35 | 35
armWithHook40 | 40
armWithHook45 | 45
armWithHook50 | 50
armWithHook55 | 55
armWithHook60 | 60
armWithHook65 | 65
armWithHook70 | 70
armWithHook75 | 75
armWithHook80 | 80
armWithHook85 | 85
armWithHook90 | 90
armWithHook95 | 95
armWithHook100 | 100
armWithHook105 | 105
armWithHook110 | 110
armWithHook115 | 115
armWithHook120 | 120
armWithHook125 | 125
armWithHook130 | 130
armWithHook135 | 135
armWithHook140 | 140
armWithHook145 | 145
armWithHook150 | 150
armWithHook155 | 155

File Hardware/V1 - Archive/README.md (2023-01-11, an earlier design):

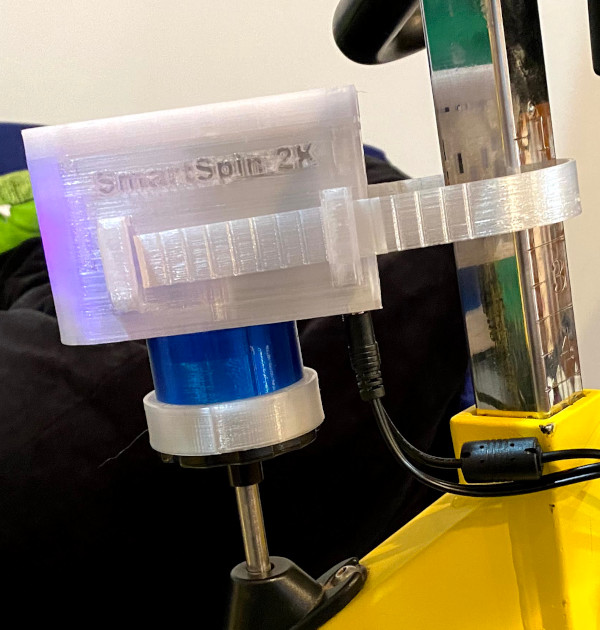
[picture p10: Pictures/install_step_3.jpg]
Hardware 1.0


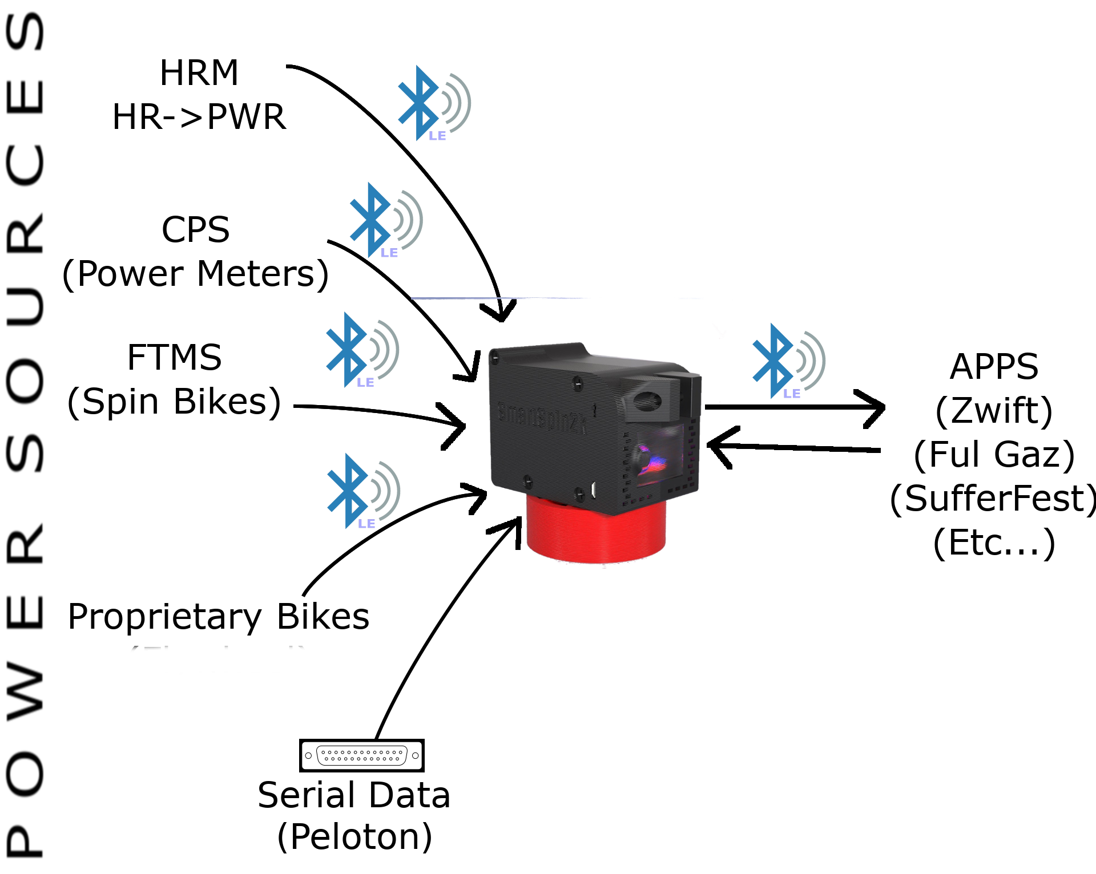
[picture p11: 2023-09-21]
Pictures/Communications_Overview.png

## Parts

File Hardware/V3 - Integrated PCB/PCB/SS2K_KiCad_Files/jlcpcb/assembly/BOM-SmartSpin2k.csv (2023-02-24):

Id | Designator | Package | Quantity | Designation | Supplier and ref
1 | C6 | C_0805_2012Metric | 1 | 22nF(50V)
2 | R6 | R_0402_1005Metric | 1 | 1k
3 | C7,C19 | CP_Elec_8x10 | 2 | 100uF(50V)
4 | D3,D1,D2,D9 | LED_0603_1608Metric | 4 | LED_Small
5 | R19 | R_0402_1005Metric | 1 | 549
6 | C32 | C_0603_1608Metric | 1 | 10uF
7 | U6 | SOT-223-3_TabPin2 | 1 | LM1117-3.3
8 | C1 | C_0805_2012Metric | 1 | 10uF(50V)
9 | U4 | SOIC-8-1EP_3.9x4.9mm_P1.27mm_EP2.514x3.2mm | 1 | TPS5430DDA
10 | SW2,SW1 | SW_Push_SPST_NO_Alps_SKRK | 2 | SW_Push
11 | S1 | SW_SPDT_CK-JS102011SAQN | 1 | EG1218
12 | D5,D4,D6 | D_0603_1608Metric | 3 | D_TVS
13 | C2,C15,C13 | C_0402_1005Metric | 3 | 0.1uF(10%)
14 | Q2,Q1 | SOT-23 | 2 | S8050
15 | C18 | C_1206_3216Metric | 1 | 4.7uF(50V)
16 | C3 | C_1206_3216Metric | 1 | 10uF(50V)
17 | R3,R23,R22,R8,R7 | R_0402_1005Metric | 5 | 10k
18 | C20,C17,C23,C21,C29,C27,C22 | C_0402_1005Metric | 7 | 0.1uF
19 | R4,R1,R5 | R_0402_1005Metric | 3 | 0(5%)
20 | R17 | R_0805_2012Metric | 1 | 20k
21 | U2 | QFN-28-1EP_5x5mm_P0.5mm_EP3.75x3.75mm | 1 | TMC2209-LA-T
22 | C28 | C_0805_2012Metric | 1 | 0.01uF
23 | C14,C5,C4 | C_0805_2012Metric | 3 | 100nF(50V)
24 | C12 | C_0805_2012Metric | 1 | 100nF(10V)
25 | R14 | R_0402_1005Metric | 1 | 100k
26 | J4 | USB_Micro_B_Female_10118194-0001LF | 1 | 10118194-0001LF
27 | R9,R12,R13,R24 | R_0402_1005Metric | 4 | 330
28 | R20 | R_0603_1608Metric | 1 | 5.9k
29 | C8 | C_0805_2012Metric | 1 | 4.7uF(6V3)
30 | R21 | R_0402_1005Metric | 1 | 4.7k
31 | U1 | ESP32-WROOM-32 | 1 | ESP32-WROOM-32D
32 | D7,D8 | D_SMA | 2 | D_Schottky
33 | C9 | C_0603_1608Metric | 1 | 1uF(50V)
34 | C11,C10 | C_0603_1608Metric | 2 | 1uF
35 | R18 | R_0402_1005Metric | 1 | 22k
36 | C16 | C_0402_1005Metric | 1 | 2.2uF
37 | U3 | MAX3232IPWR | 1 | MAX3232
38 | R11,R10 | R_0402_1005Metric | 2 | 200
39 | C30 | C_1206_3216Metric | 1 | 100uF
40 | C31 | C_0805_2012Metric | 1 | 1.5nF
41 | R16,R15 | R_1206_3216Metric | 2 | 80m
42 | C25 | C_0805_2012Metric | 1 | 1.0uF
43 | U5 | QFN-28-1EP_5x5mm_P0.5mm_EP3.35x3.35mm | 1 | INTERFACE-CP2102-GMR(QFN28)
44 | C26 | C_0805_2012Metric | 1 | 150pF
45 | R2 | R_0402_1005Metric | 1 | 1M
46 | L1 | L_12x12mm_H8mm | 1 | L_Iron
47 | C24 | C_0805_2012Metric | 1 | 4.7uF
48 | J1,J2 | JST_XH_B4B-XH-AM_1x04_P2.50mm_Vertical | 2 | B4B-XH-AMLFSN
49 | J3 | JST_XH_B8B-XH-AM_1x08_P2.50mm_Vertical | 1 | B8B-XH-A_LFSN

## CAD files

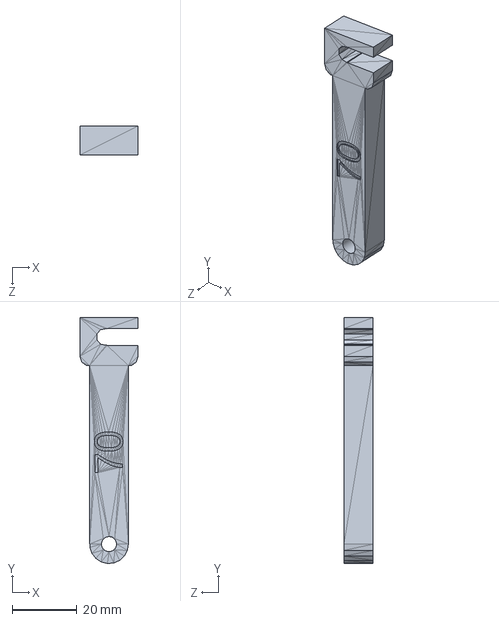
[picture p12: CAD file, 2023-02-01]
Hardware/Common Assets/Arm/CAD/Arm_70_For_Assembly_Only.SLDPRT
18.0 x 76.0 x 9.00 mm

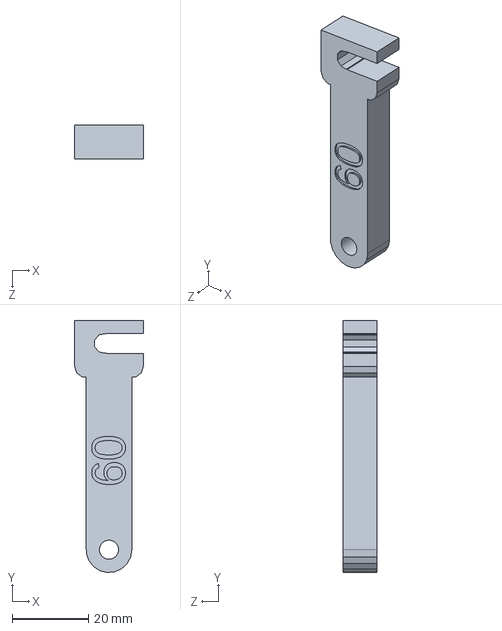
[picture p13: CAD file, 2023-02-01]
Hardware/Common Assets/Arm/CAD/Arm_60_For_Assembly_Only.SLDPRT
18.0 x 66.0 x 9.00 mm

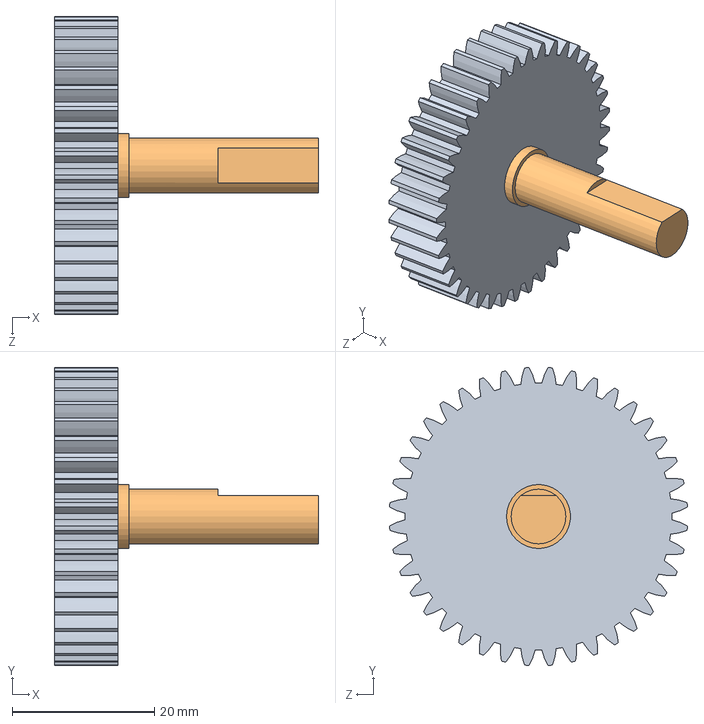
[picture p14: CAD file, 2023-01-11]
Hardware/Common Assets/Gears/CAD/40_Tooth_Mod1.SLDASM
37.2 x 41.9 x 41.9 mm
Metric - Spur gear 1M 40T 20PA 9FW ---S40N75H50L4N
Gear_Shaft

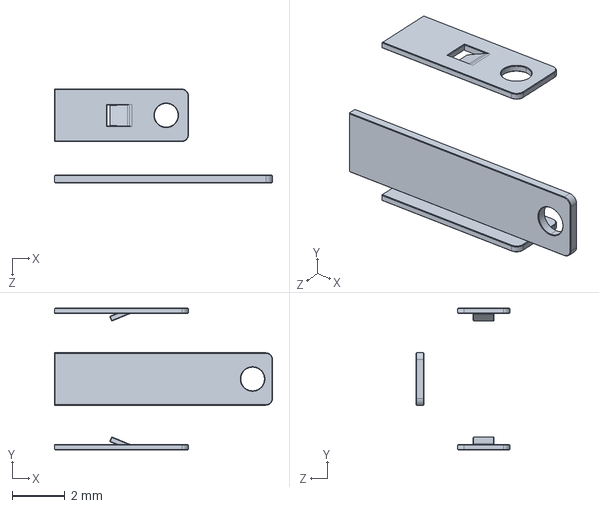
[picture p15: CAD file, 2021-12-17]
Hardware/V2 - Through Hole/Universal Mount/Case/CAD/Connectors/3.5mmJack.SLDASM
8.30 x 5.40 x 3.58 mm

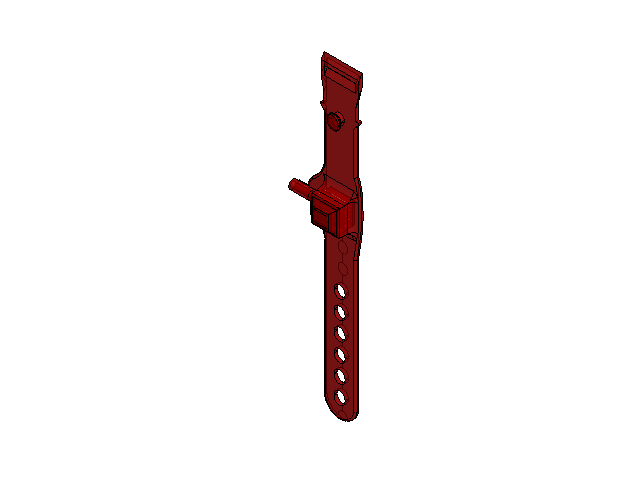
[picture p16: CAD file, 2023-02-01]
Hardware/Common Assets/Shifters/CAD/Shifter_Assembly.SLDASM
Strap
Plug
Switch

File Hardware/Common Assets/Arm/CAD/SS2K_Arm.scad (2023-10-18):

/*All in one Arm*/

//Length of arm
armLength=61.5; // 


//////////////////////////
//Width of the arm
armWidth=9;

//Height of the arm
armHeight = 12;

//bolt diameter
boltDiameter = 5.25;

//hook diameter
hookDiameter = 5.2;
///////////////////////////

//Required to add roundness to parts
$fa = 1;
$fs = 0.5;

difference(){
union(){ 
    //round part at the end
    translate([0,-armLength/2, 0]){
    cylinder(armWidth, armHeight/2, armHeight/2, true);
    }
    //main arm
    cube([armHeight, armLength, armWidth], true);
    translate([0,(armLength/2)-(armHeight/2), 0]){
    cube([armHeight*1.5, armHeight, armWidth], true);   
    //radius above hook   
    translate([-armHeight + armHeight/2,-armHeight/2, 0]){
    cylinder(armWidth, armHeight/4, armHeight/4, true);
    }
    //Radius below hook
    translate([armHeight - armHeight/2,-armHeight/2, 0]){
    cylinder(armWidth, armHeight/4, armHeight/4, true);
    } 
        
   }
}

// bolt hole
translate([0,-armLength/2, 0]){
cylinder(armWidth +2, boltDiameter/2, boltDiameter/2, true);
}

// hook hole
translate([-hookDiameter/4,(armLength/2)-(armHeight/2), 0]){
cylinder(armWidth +2, hookDiameter/2, hookDiameter/2, true);
}

//hook slot
translate([armHeight/1.5,(armLength/2)-(armHeight/2), 0]){    
    cube([armHeight+hookDiameter, hookDiameter, armWidth +2], true);
}

//size text
//hook slot
translate([0,0,armWidth/2-.5]){  
rotate([0,0,90]){ 
    linear_extrude(2){
    text(str(armLength),  size = armHeight-3, halign = "right", valign = "center");
}}}

}

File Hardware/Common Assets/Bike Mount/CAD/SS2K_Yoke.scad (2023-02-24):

/*All in one yoke*/

// Length of yoke
yokeLength = 55;

// Width of the yoke opening
yokeWidth = 32;

// Thickness of the yoke arms
yokeThickness = 5.5;

// YokeHeight
yokeHeight = 30;

// Strap Slot Thickness
strapThickness = 2;

// Strap Slot Height
strapHeight = 15;

///Expert Options Below///
// height of the arm
armHeight = 15;

// Overall width of the attachment arm
armAttachWidth = 20;

// bolt diameter
boltDiameter = 5.5;

// armSlotWidth
armSlotWidth = 9.2;
///////////////////////////
module strapHolder()
{
    translate([ -yokeLength / 2, yokeWidth / 2 + yokeThickness / 2, 0 ])
    {
        difference()
        {
            hull()
            {
                translate([ -yokeThickness / 2, yokeThickness * 1.5, 0 ]) cylinder(yokeHeight, yokeThickness / 2, yokeThickness / 2);
                cylinder(yokeHeight, yokeThickness / 2, yokeThickness / 2);
            }
            rotate([ 0, 0, 30 ])
            {
                translate([ -yokeThickness * 2, yokeThickness / 1.3, yokeHeight / 2 - strapHeight / 2 ])
                {
                    cube([ yokeLength, strapThickness, strapHeight ]);
                }
            }
        }
    }
}

module ovalTube()
{
    difference()
    {
        hull()
        {
            cylinder(yokeHeight, yokeWidth / 2 + yokeThickness, yokeWidth / 2 + yokeThickness);
            translate([ -yokeWidth + yokeThickness, 0, yokeHeight / 2 ])
            {
                cube([ yokeLength, yokeWidth + yokeThickness * 2, yokeHeight ], true);
            }
        }
        // middle of yoke
        cylinder(yokeHeight + 5, yokeWidth / 2, yokeWidth / 2);
        translate([ -yokeLength / 2, 0, yokeHeight / 2 ])
        {
            cube([ yokeLength, yokeWidth, yokeHeight + 5 ], true);
        }
        // end cut
        translate([ -yokeLength, 0, yokeHeight / 2 ])
        {
            cube([ yokeLength, yokeWidth * 2, yokeHeight + 5 ], true);
        }
    }
}

difference()
{
    union()
    {
        // main attach point
        translate([ 0, 0, 0 ])
        {
            cube([ armAttachWidth * 1.5, armAttachWidth, armHeight ], true);
            // radius above hook
        }
        // yoke
        translate([ -armAttachWidth - yokeWidth / 2 + yokeThickness / 2, 0, -armHeight / 2 ])
        {
            ovalTube();
            strapHolder();
            mirror([ 0, 1, 0 ]) strapHolder();
        }
    }

    // bolt hole
    translate([ armAttachWidth / 3, 0, 0 ])
    {
        rotate([ 0, 90, 90 ])
        {
            cylinder(armHeight * 4, boltDiameter / 2, boltDiameter / 2, true);
            // head recess
            translate([ 0, 0, -armAttachWidth / 1.3 ])
            {
                cylinder(armHeight, boltDiameter, boltDiameter, true);
            }
            // Nut recess
            translate([ 0, 0, armAttachWidth / 1.3 ])
            {
                cube([ 5.2, 8.9, boltDiameter * 2.7 ], true);
                rotate([ 00, 00, 60 ])
                {
                    cube([ 5.2, 8.9, boltDiameter * 2.7 ], true);
                }
                rotate([ 0, 0, 120 ])
                {
                    cube([ 5.2, 8.9, boltDiameter * 2.7 ], true);
                }
            }
        }
    }

    // hook hole
    translate([ -armSlotWidth / 4, 0, 0 ])
    {
        cylinder(armHeight + 2, armSlotWidth / 2, armSlotWidth / 2, true);
    }

    // hook slot
    translate([ armAttachWidth / 1.5, 0, 0 ])
    {
        cube([ armAttachWidth + armSlotWidth, armSlotWidth, armHeight + 2 ], true);
    }
}

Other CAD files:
Hardware/V3 - Integrated PCB/PCB/SolidWorks/SmartSpin2k.SLDASM
Hardware/V3 - Integrated PCB/PCB/SolidWorks/USB_Micro-B_Molex_47346-0001.SLDASM
Hardware/V3 - Integrated PCB/PCB/SolidWorks/R_0805_2012Metric.SLDASM
Hardware/Common Assets/Shifters/CAD/PCB Switch 01.SLDASM
Hardware/Common Assets/Shifters/CAD/Bottom_Half.SLDASM
Hardware/V3 - Integrated PCB/PCB/SolidWorks/SW_SPDT_PCM12.SLDASM
Hardware/Common Assets/Shifters/CAD/Shifter_Cover v10 v3.SLDASM
Hardware/V3 - Integrated PCB/PCB/SolidWorks/JST_XH_B8B-XH-A_1x08_P2.50mm_Vertical.SLDASM
Hardware/V3 - Integrated PCB/PCB/SolidWorks/SW_SPST_B3U-1000P-B.SLDASM
Hardware/V2 - Through Hole/Ultra Short Mod/Case/CAD/Connectors/54-00063_ASM.SLDASM
Hardware/V3 - Integrated PCB/Case/Case/CAD/Connectors/54-00063_ASM.SLDASM
Hardware/V3 - Integrated PCB/PCB/SolidWorks/ESP32-WROOM-32.SLDASM
Hardware/Case Version1/Cases/Bottom_Case.stl
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

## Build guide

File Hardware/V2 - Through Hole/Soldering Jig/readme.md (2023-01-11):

# Soldering Jig

While the PCB is quite simple and easy to solder by hand, it may be daunting for new users.  This jig was originally created to help reduce the time and effort involved in making PCB's.  By placing all the small components exactly where they need to be and rendering them immobile, it becomes hugely simpler for someone to solder the PCB with little to no soldering experience.

WARNING: It's advisable to print this with ABS or PETG due to their higher melting temperatures.  While the PCB should be an effective insulator and shield the plastic from heat, do not let the tip of the iron dwell for too long as the printed plastic may warp or melt.  This print has been tested with ABS.  

## Instructions

- Insert capacitors and resistors directly into the PCB.  
- Insert the JST connectors, Recom, and stepper motor controller into their respective slots.  Be mindful of orientation.
- Apply PCB over the soldering jig
- Solder PCB


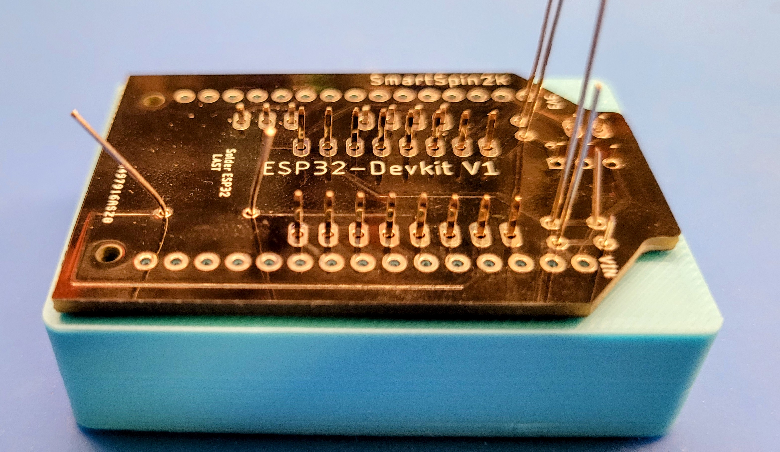
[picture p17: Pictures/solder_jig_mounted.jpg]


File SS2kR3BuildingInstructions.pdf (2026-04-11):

# SmartSpin2k V3 Building Instructions

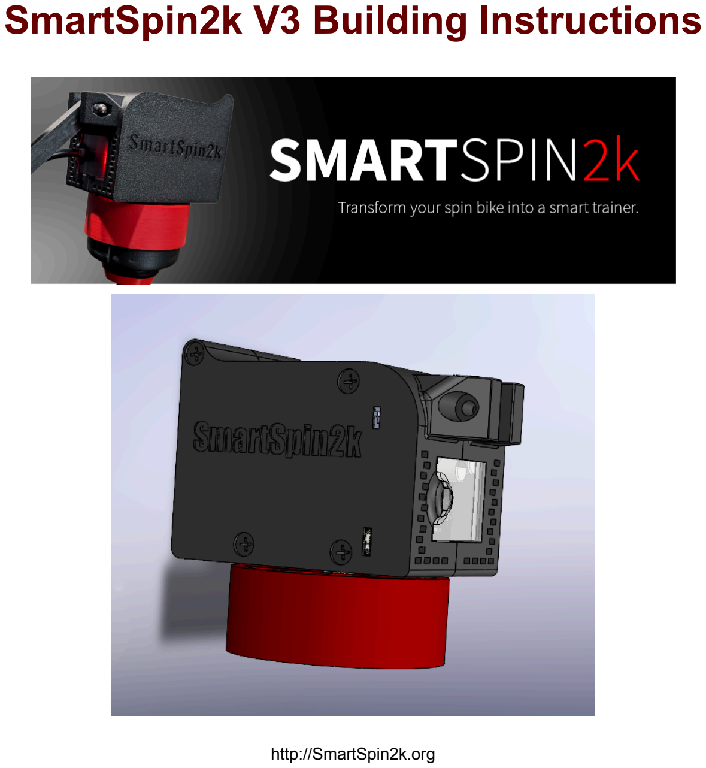
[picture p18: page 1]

http://SmartSpin2k.org

Transform your spin bike
into a smart trainer! | WWW.SMARTSPIN2K.ORG

### TABLE OF CONTENTS

### PRINTING GUIDELINES

### HARDWARE

### OVERVIEW

### AXLE ASSEMBLY

### STEPPER INSTALLATION

### PCB INSTALLATION

### JOINING CASE HALVES

### BUILDING SHIFTERS

### INSTALL BIKE ARM

### INSTALL BIKE MOUNT

### MOUNT SMARTSPIN2K ON BIKE

# PRINTING GUIDELINES

We’ve tested a lot of different materials and techniques, but here are our recommended guidelines:

3D PRINTING PROCESS
FDM

MATERIAL
ABS, ASA, PETG or PA

LAYER HEIGHT
Design optimized for .3mm

EXTRUSION WIDTH
Design optimized for .6mm
But prints well with .4mm as well.

INFILL TYPE
Grid, Gyroid, Honeycomb, Triangle or Cubic

INFILL PERCENTAGE
Recommended: 40%

WALL COUNT
Recommended: 4

SOLID TOP/BOTTOM LAYERS
Recommended: 5

We suggest printing the knob cup in an accent color. Our preferred accent color is RED. The window should be printed in a TRANSLUCENT PETG to let the LEDs show through. The rest of the design can be printed in BLACK.

# HARDWARE

SmartSpin2k has been designed to minimize the amount of hardware you’ll need. V3 takes this approach even further.

SmartSpin2k PCB

SmartSpin2k Harness Cables

12 or 24v Wall Power Supply

38mm NEMA 17 Stepper Motor

2 x 608 Skate Bearings

5/16" x 1-1/2" Hex Head Bolt

2 x 5/16” Hex Nuts

5/16” Flat Washer

4 x 2” Black Oxide Sheet Rock Screws

2 x M5 X 30mm Cap Screw (or #10x1.25”)

2 x M5 Hex Nut (or #10)

Zip Ties or Velcro Strap

Shifter PCB

2 x Buna N70143 O-Rings

NOTE: Only one of each item is required unless an x is
indicated to imply multiples. Refer to the documentation (https://docs.smartspin2k.com) for questions about where to obtain parts.

# OVERVIEW

This is an exploded view of the main SmartSpin2k body. Feel free to come back to it if you have
any general questions on where parts fit.

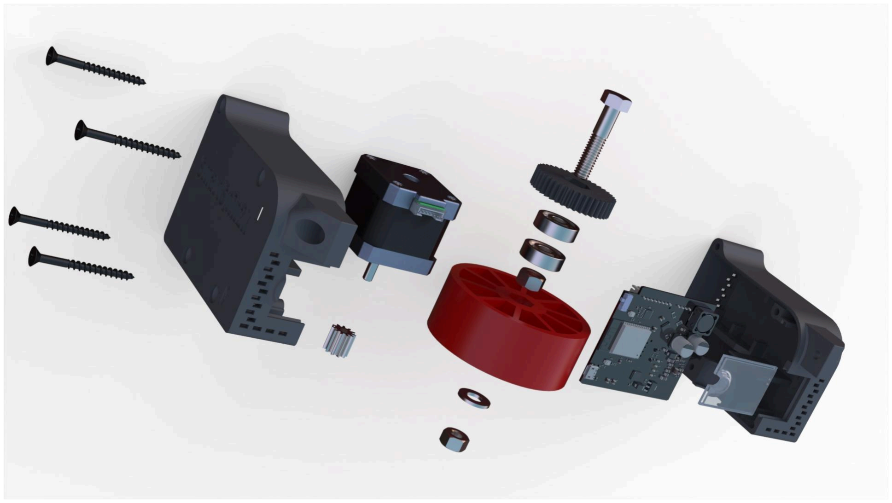
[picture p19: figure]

# AXLE ASSEMBLY

For this step, you’ll need the 5/16” bolt,
both 608 bearings, the washer and both nuts. Blue threadlocker is also recommended
on the nuts.

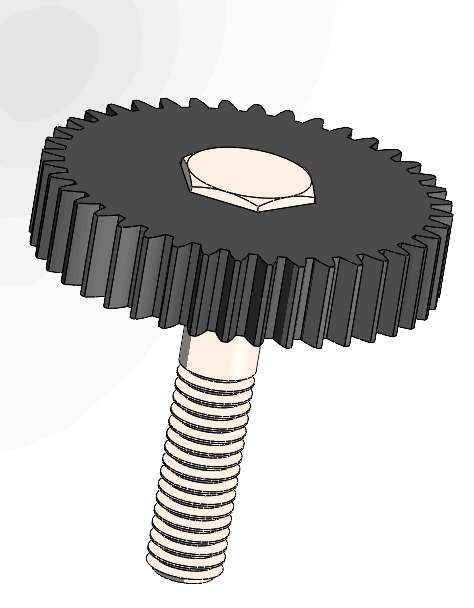
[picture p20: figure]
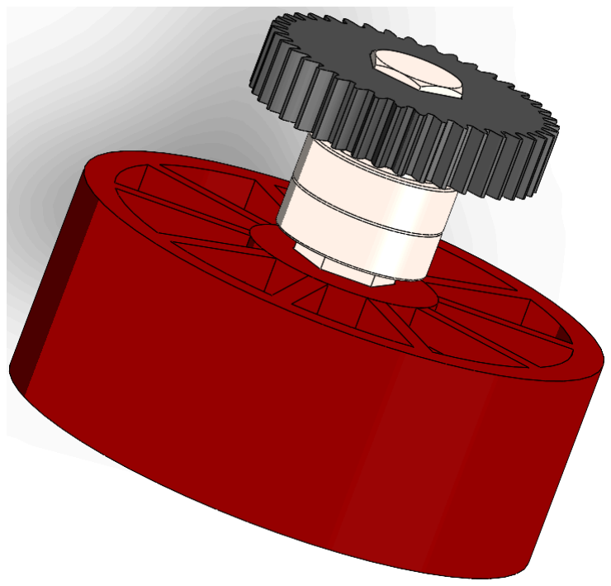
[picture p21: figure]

Insert the bolt
into the 40t gear.

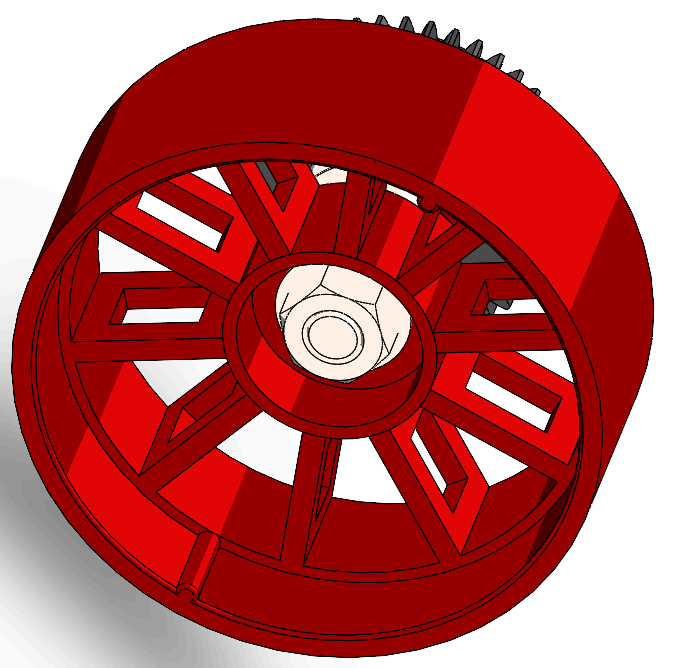
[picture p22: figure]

Install both 608
skate bearings
and one nut onto
the bolt.

(Note: One
double-wide bearing
can be used in place
of the two 608 skate

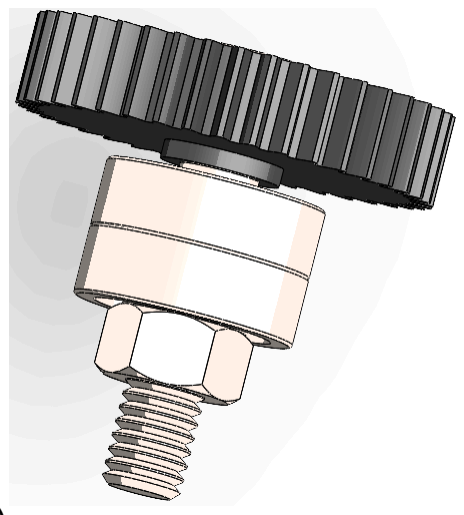
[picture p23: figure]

bearings, if available.)

Slide the knob cup
onto the axle
assembly.

Install the washer
and the final nut
onto the assembly.
Tighten by holding
the gear in your
hand with a cloth
and a ratchet on
the nut.

# STEPPER MOTOR INSTALLATION

It’s time to put the motor
into the case!

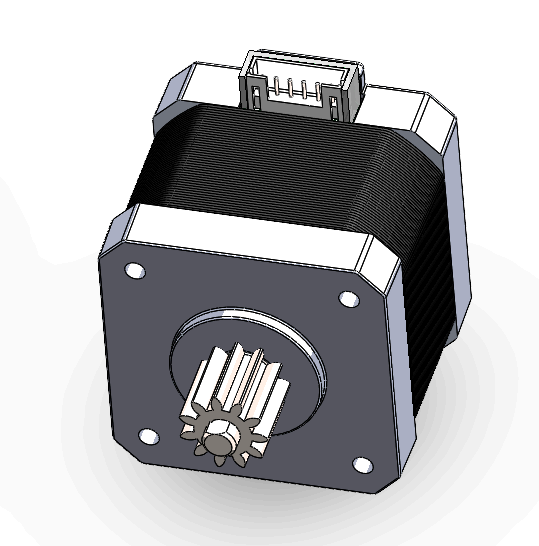
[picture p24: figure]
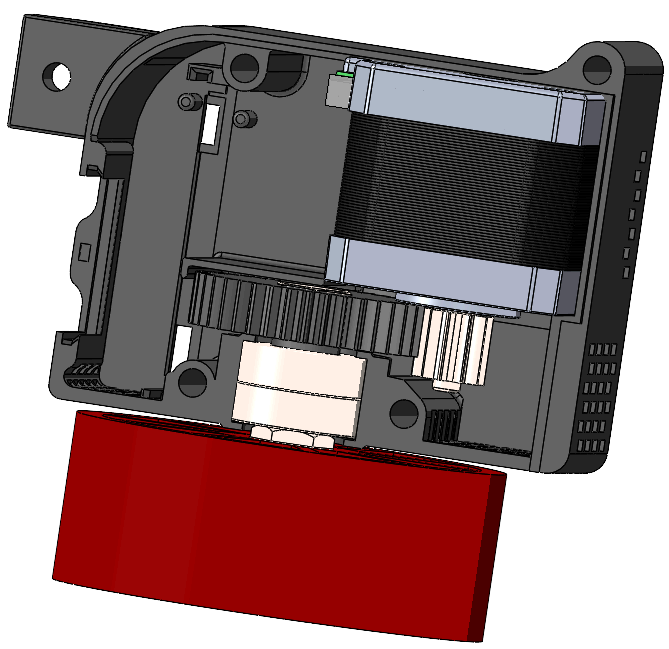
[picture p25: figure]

Line up the flat side
and press the gear
onto the D shaft.
Depending on printer
tolerances, you may
need to heat the gear
to prevent damaging it.

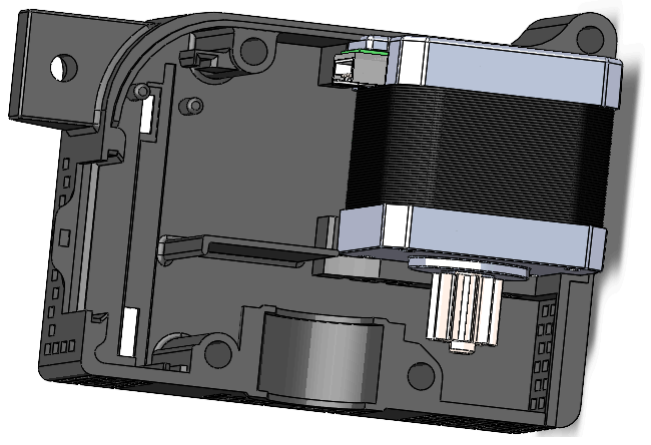
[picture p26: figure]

Place the stepper motor
into the slot in grooves
in the left case half.

Insert the axle
assembly into the
left case half.

# PCB INSTALLATION

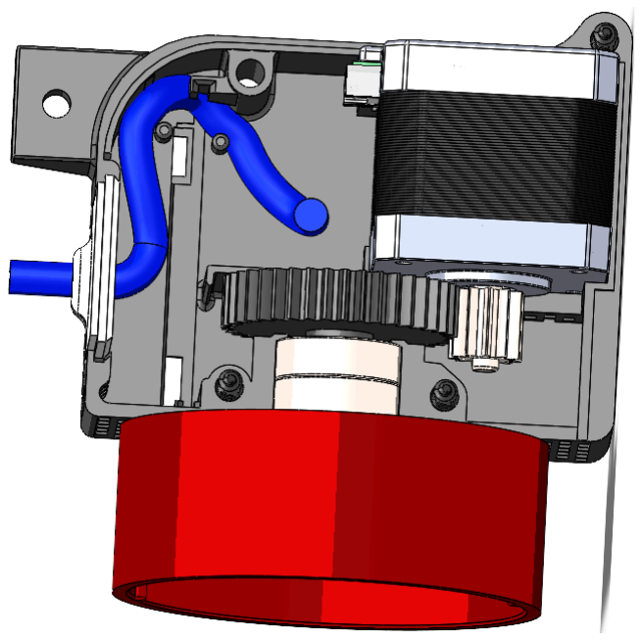
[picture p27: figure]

Prior to PCB install, lay the main cable (blue) on the side of the case and out of the hole in the window
using the two pegs in the case
to hold the wire in place. Slide the window into place. Leave the connector disconnected until the PCB is in place.

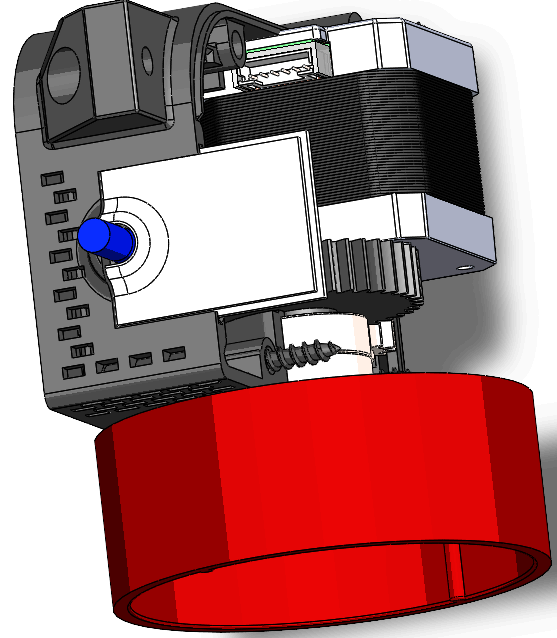
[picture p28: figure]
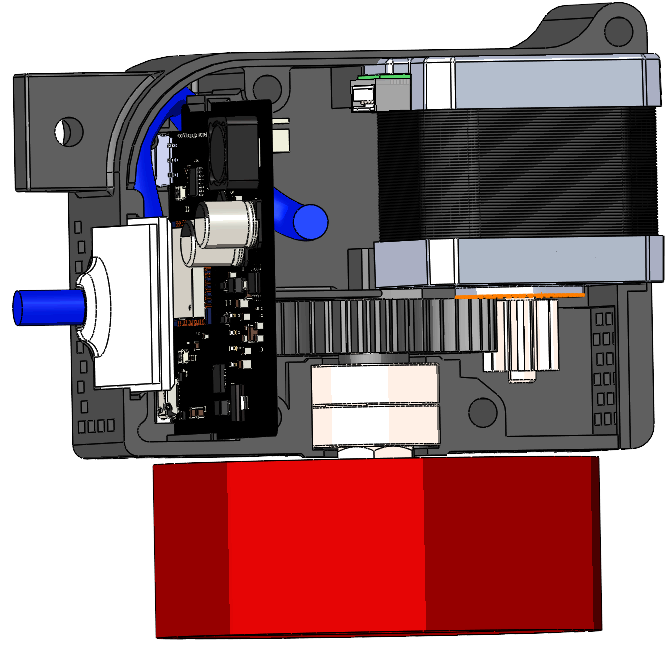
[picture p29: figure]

Carefully slide the PCB
into the grooves on the
case half being careful
not to pinch the cable.
There is a cutout in the
PCB to let the cable
pass through.

Once the board is in place, both the stepper motor cable and the main cable can be connected. If Solidworks gave me cable routing, I’d show that to you. :)

# JOINING CASE HALVES

Follow along with the pictures in the instructions below. Use your imagination, and pretend there’s a cable sticking out from the appropriate hole in the window.

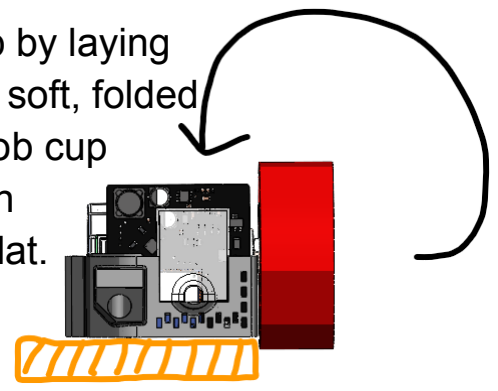
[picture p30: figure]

Prepare for this step by laying the SmartSpin2k on soft, folded towel so that the knob cup doesn’t interfere with
the assembly lying flat.

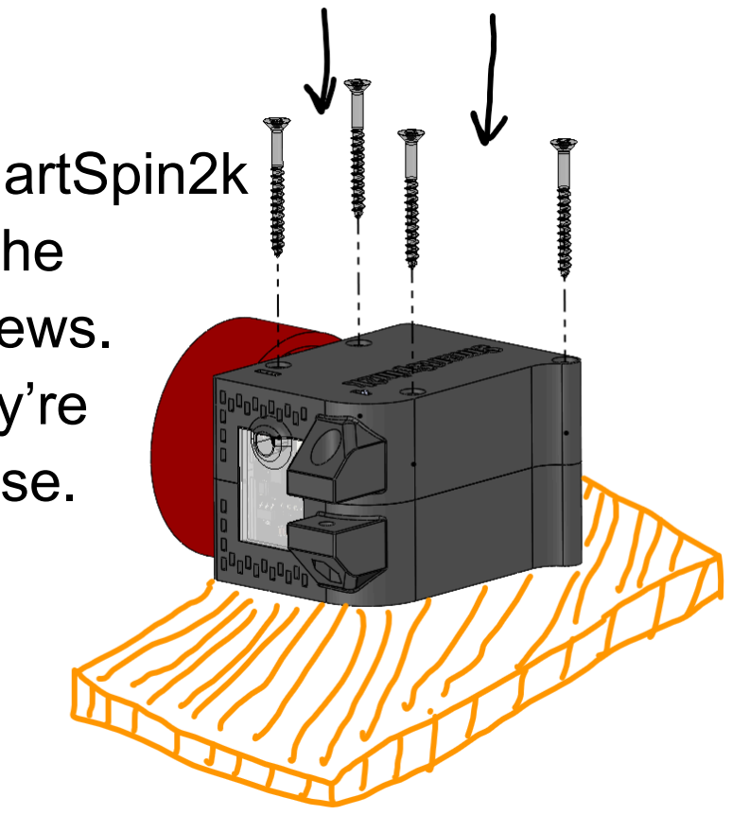
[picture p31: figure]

Now, flip the SmartSpin2k
over and insert the
4 sheet rock screws.
Tighten until they’re
flush with the case.

Evenly slide the opposite

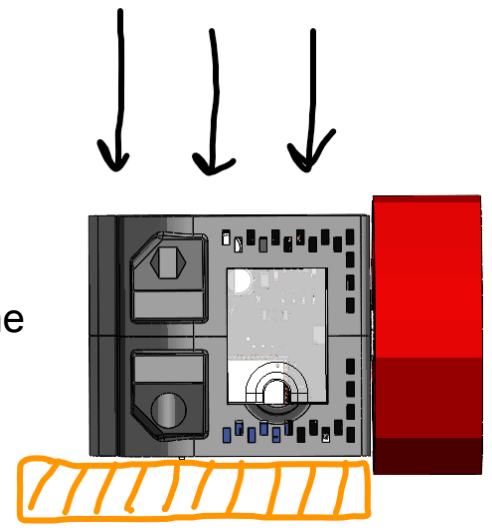
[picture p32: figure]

case half onto the other side. There is a locking tab near the rear vents that should click into place.

# BUILDING SHIFTERS (PCB)

The PCB shifter is the recommended approach for most users as it does not require any soldering or special tools for assembly. It is printed in two parts. The TPU-Shifters.stl file should be printed in TPU
or another flexible material. The base can be printed
in any reasonably sturdy plastic.

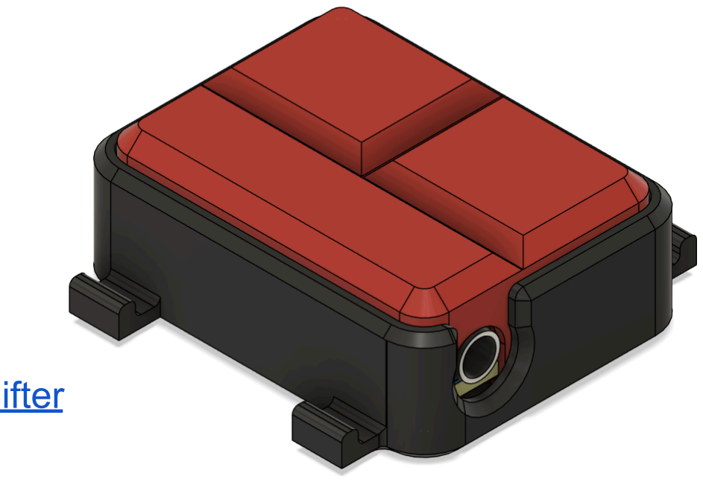
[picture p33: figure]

Shifter files: https://github.com/eMadman/SmartSpin2K-Shifter

First, start by inserting the PCB into the TPU-Shifter housing. Use a pointed tool like a fine screwdriver to help wrap the

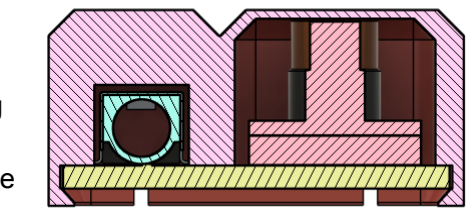
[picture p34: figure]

TPU around the circuit board. The housing will completely wrap around the PCB as pictured in the cutaway to the right. Test the buttons. They should feel nice and clicky.

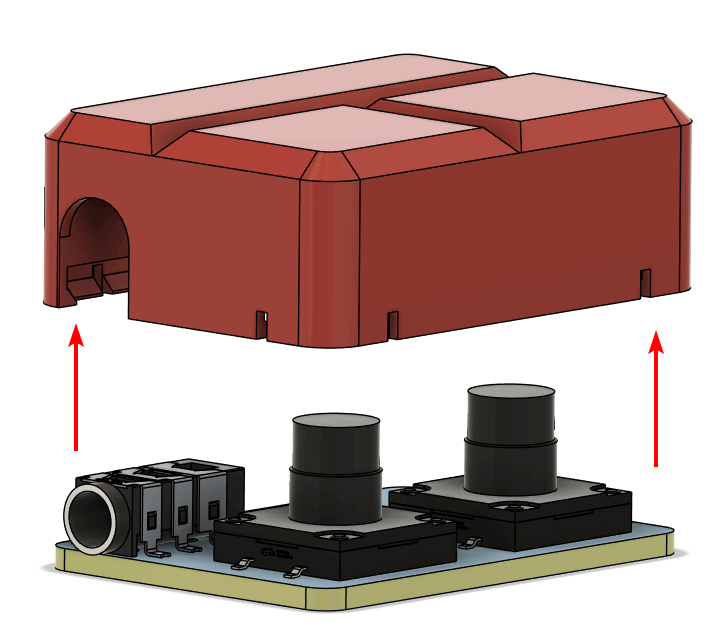
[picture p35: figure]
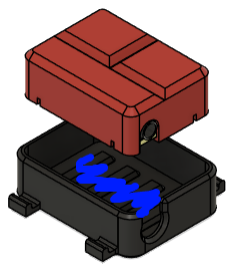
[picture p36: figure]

Now you’re ready to insert the button assembly into the main body. Working quickly, apply some hot glue into the shifter body, then insert the button assembly. Press gently from above, being careful not to burn your fingers on any excess glue that squeezes out the case from the headphone area.
You can carve this out with a hobby knife once it cools.

TIP: While we recommend hot glue, any flexible adhesive compatible with TPU and your chosen plastic will work well.

Once completed, secure shifter onto handlebar with Buna N70143 o-rings.

# INSTALL BIKE ARM

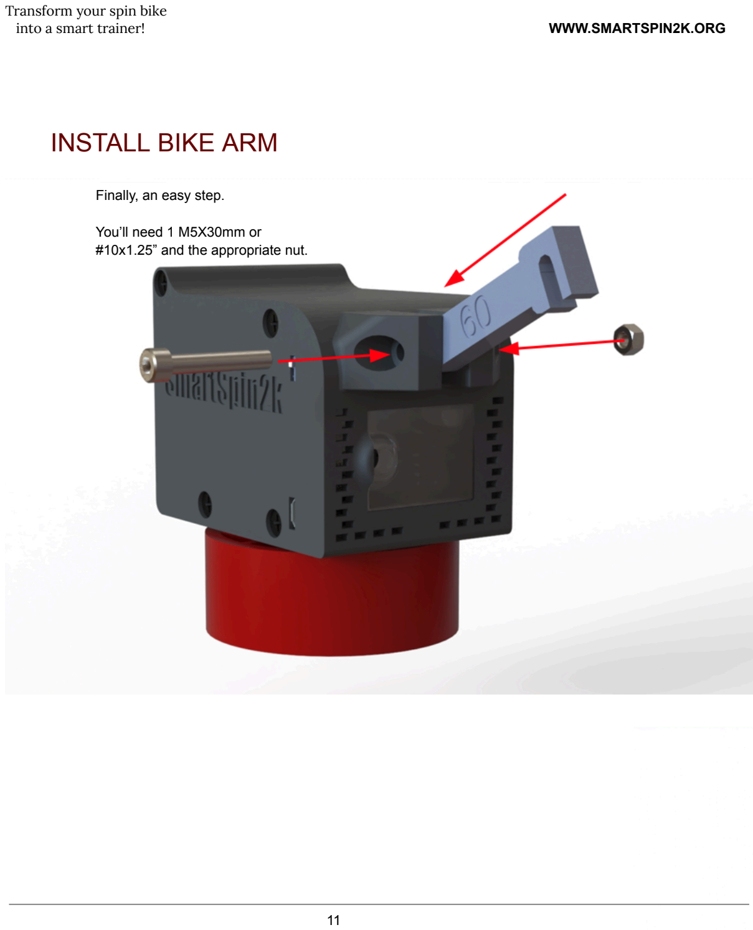
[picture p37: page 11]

Finally, an easy step.

You’ll need 1 M5X30mm or
#10x1.25” and the appropriate nut.

# INSTALL BIKE MOUNT

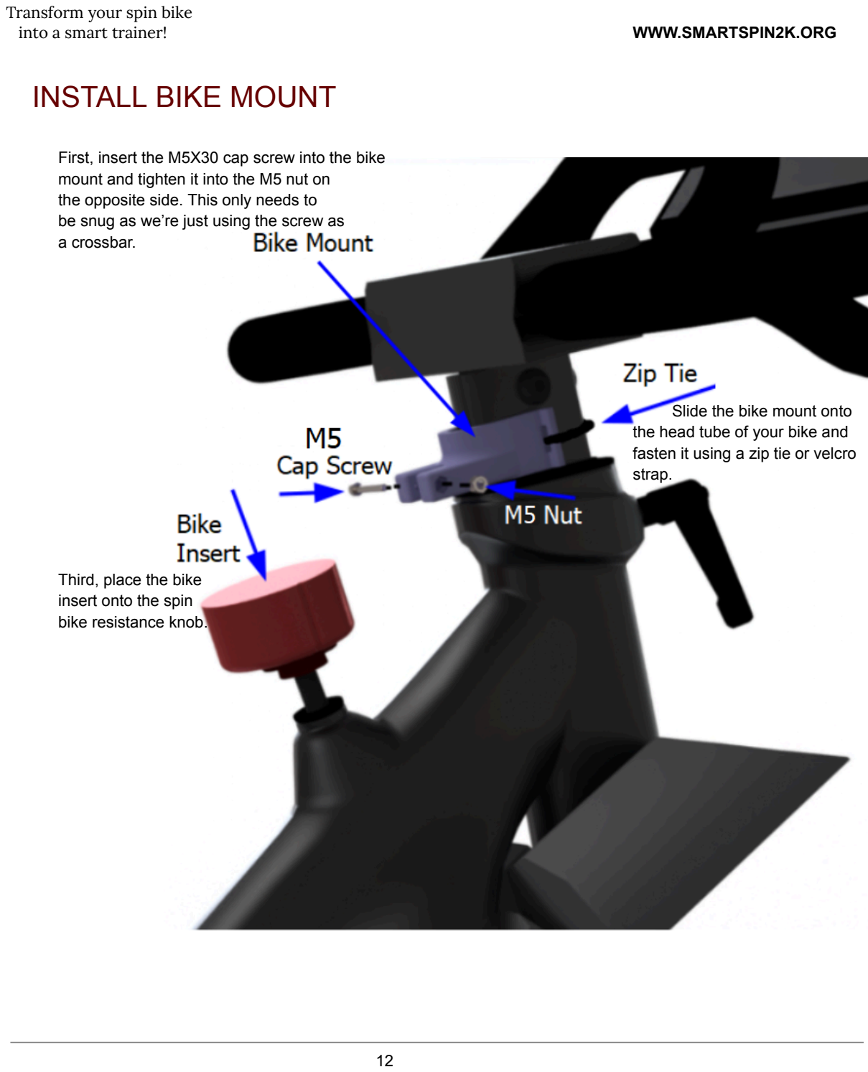
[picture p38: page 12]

First, insert the M5X30 cap screw into the bike mount and tighten it into the M5 nut on
the opposite side. This only needs to
be snug as we’re just using the screw as
a crossbar.

Slide the bike mount onto
the head tube of your bike and fasten it using a zip tie or velcro strap.

Third, place the bike
insert onto the spin
bike resistance knob.

# MOUNT SMARTSPIN2K ON BIKE

Line up the indexing grooves on the
knob cup with the ones on the bike insert, and lower the SmartSpin2k into place.

Then rotate the bike arm down onto the cap screw in the bike mount.

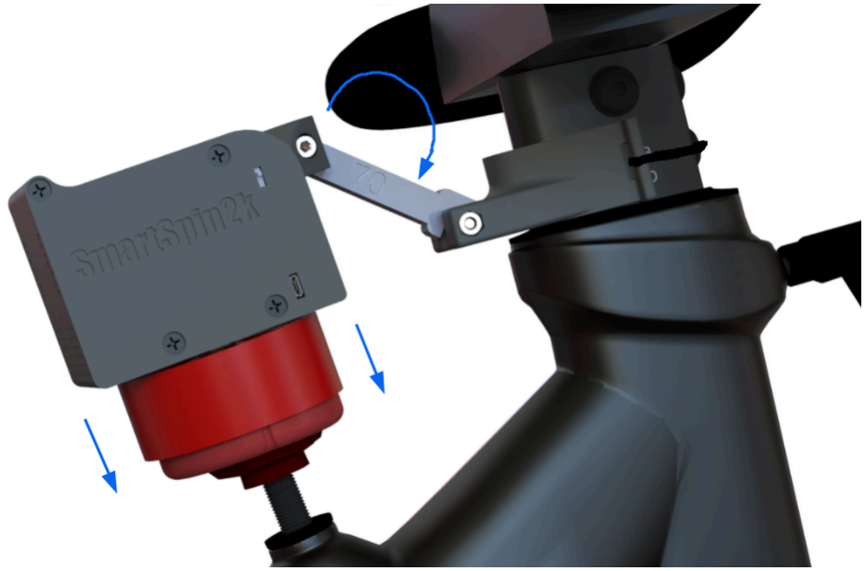
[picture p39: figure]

# FINISHED ASSEMBLY

Congratulations. You deserve a break!

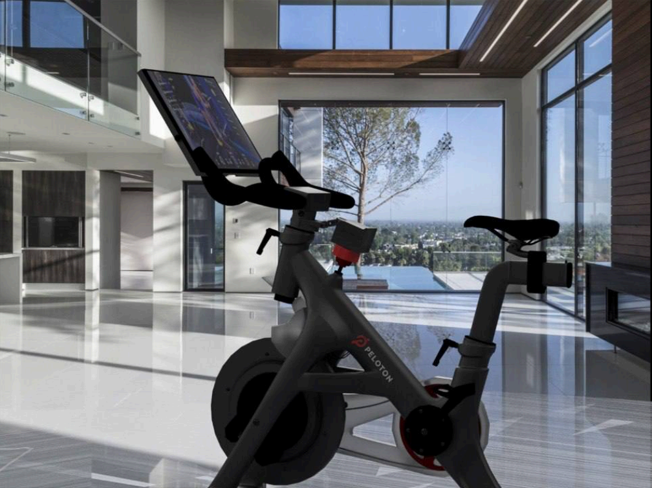
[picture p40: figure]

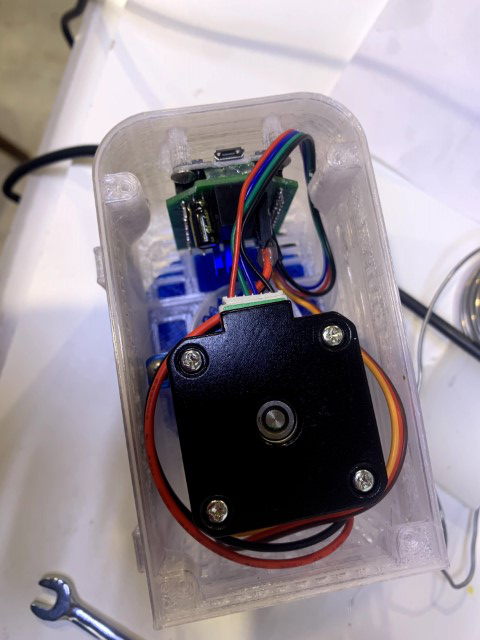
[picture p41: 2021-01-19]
Pictures/Assembly/IMG_7258.jpg

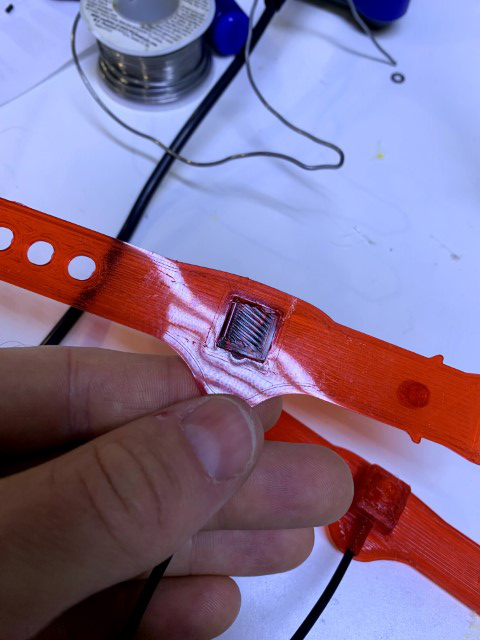
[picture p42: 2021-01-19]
Pictures/Assembly/IMG_7249.jpg

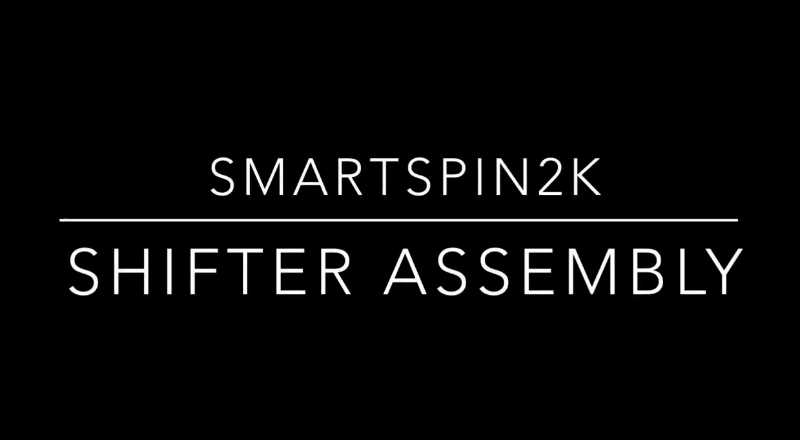
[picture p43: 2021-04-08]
Pictures/ShifterAssemble.png

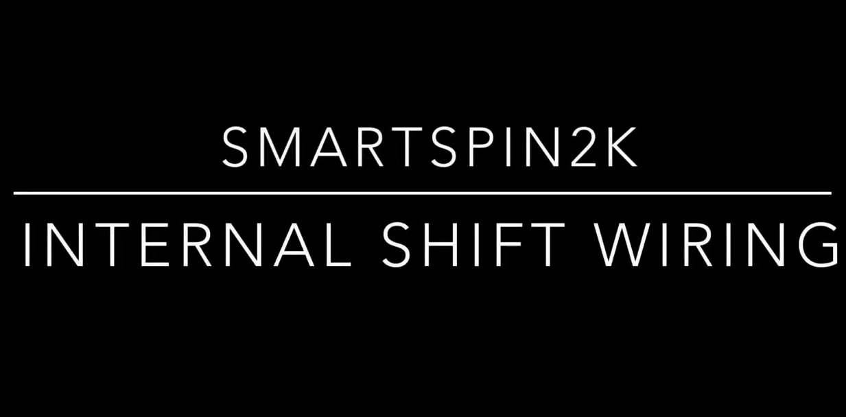
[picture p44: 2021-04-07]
Pictures/Shift_Wiring.png

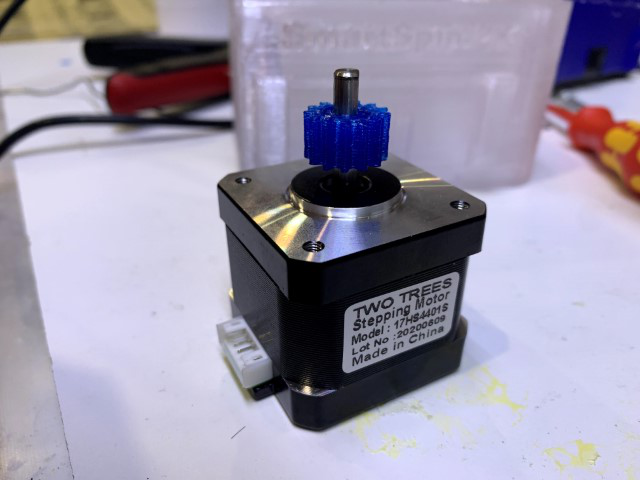
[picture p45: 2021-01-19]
Pictures/Assembly/IMG_7239.jpg

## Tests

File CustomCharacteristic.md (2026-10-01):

Please use and refer to the following notes for use of the custom characteristic:

Custom Characteristic for userConfig Variable manipulation via BLE

SMARTSPIN2K_SERVICE_UUID        "77776277-7877-7774-4466-896665500000"
SMARTSPIN2K_CHARACTERISTIC_UUID "77776277-7877-7774-4466-896665500001"

The same service and characteristic are published in the DirCon mDNS service.
A DirCon client sends the protocol bytes in a characteristic-write request and receives the custom-characteristic response bytes in that write response.
Subscribed DirCon clients also receive changed-value notifications.

The primary BLE advertisement includes the current Wi-Fi IPv4 address in manufacturer-specific data.
The device name and SmartSpin2k service UUID remain in the scan response. The payload is:

| Offset | Size | Meaning |
|---|---|---|
| 0 | 2 | Reserved development company identifier `0xFFFF`, little-endian |
| 2 | 2 | ASCII payload marker `SS` |
| 4 | 1 | Payload format version (`0x01`) |
| 5 | 4 | IPv4 address octets in network/display order |

An example follows to read/write 26.3kph to simulatedSpeed:

simulatedSpeed is a float and first needs to be converted to int by *10 for transmission, so convert 26.3kph to 263 (multiply by 10)
Decimal 263 == hexadecimal 0107 but the data needs to be converted to LSO, MSO to match the rest of the BLE spec so 263 == 0x07, 0x01 (LSO,MSO)

So,

If client wants to write (0x02) int value 263 (0x07 0x01) to simulatedSpeed(0x06):

Client Writes:
0x02, 0x06, 0x07, 0x01
(operator, variable, LSO, MSO)

Server will then indicate:
0x80, 0x06, 0x07, 0x01 
(success),(simulatedSpeed),(LSO),(MSO)

Example to read (0x01) from simulatedSpeed (0x06)

Client Writes:
0x01, 0x06
Server will then indicate:
0x80, 0x06, 0x07, 0x01 
(success),(simulatedSpeed),(0x07),(0x01)

Pay special attention to the float values. Since they have to be transmitted as an int, some are converted *100, others are converted *10.
Refer to BLE_Server.cpp for which conversions to use.

True values are >00. False are 00.

Values in first byte:

Written:
  uint8_t read        = 0x01;  // value to request read operation
  uint8_t write       = 0x02;  // Value to request write operation
  
Indicated:
  uint8_t error       = 0xff;  // value server error/unable
  uint8_t success     = 0x80;  // value for success

From BLE_common.h
//custom characteristic codes
| Variable |uint8_t| type| Notes |
|---|:-----:|-----|---|
|BLE_firmwareUpdateURL |0x01 | |Not Implemented |
|BLE_incline |0x02 |float|incline from app |
|BLE_simulatedWatts |0x03 |int  |simulated or read watts |
|BLE_simulatedHr |0x04 |int  |simulated or read HR |
|BLE_simulatedCad |0x05 |float|simulated or read cadence |
|BLE_simulatedSpeed |0x06 |float|Calculated speed |
|BLE_deviceName |0x07 | |Not Implemented |
|BLE_shiftStep |0x08 |int  |Stepper steps per shifter button press |
|BLE_stepperPower |0x09 |int  |Stepper power in ma |
|BLE_stealthChop |0x0A |bool |Stepper stealthChop on/off |
|BLE_inclineMultiplier |0x0B |float|- multiplied by incline to get steps per % gradient|
|BLE_powerCorrectionFactor |0x0C |float|.5 - 2.0 to calibrate power output |
|BLE_simulateHr |0x0D |bool | |
|BLE_simulateWatts |0x0E |bool | | 
|BLE_simulateCad |0x0F |bool | |
|BLE_FTMSMode |0x10 |bool | |
|BLE_autoUpdate |0x11 |bool |Deprecated compatibility field; always off |
|BLE_ssid |0x12 | |Not Implemented |
|BLE_password |0x13 | |Not Implemented |
|BLE_foundDevices |0x14 | |Not Implemented |
|BLE_connectedPowerMeter |0x15 | |Not Implemented |
|BLE_connectedHeartMonitor |0x16 | |Not Implemented |
|BLE_shifterPosition |0x17 |int  |That changes when a shift is preformed. |
|BLE_saveToLittlefs |0x18 |bool |01 written will save to spiffs. |
|BLE_targetPosition |0x19 |int36|Position (in steps) the motor is maintaining. |
|BLE_externalControl |0x1A |bool |01 disables internal calculation of targetPosition.|
|BLE_syncMode |0x1B |bool |01 stops motor movement for external calibration |
|BLE_powerTableData |0x27 |row  |Read/write a power-table row; first upload row queues homing|
|BLE_UDPLogging |0x2E |bool |Enable/disable UDP log streaming |
|BLE_hardwareVersion |0x2F |str  |Read-only detected hardware revision |
|BLE_BLELogging |0x30 |bool/str|Write: enable/disable BLE log streaming. Read: returns last log message|
|BLE_allSettings |0x31 |JSON |Read-only chunked snapshot of all user settings |
|BLE_gearTeeth |0x34 |array|Packed front/rear tooth pairs; metadata/indexed reads |
|BLE_gearPreset |0x35 |uint16|0 = tooth profile/Unlimited, 1 = Mixed Terrain 1x24 |

*syncMode will disable the movement of the stepper motor by forcing stepperPosition = targetPosition prior to the motor control. While this mode is enabled, it allows the client to set parameters like incline and shifterPosition without moving the motor from it's current position. Once the parameters are set, this mode should be turned back off and SS2K will resume normal operation.

The first power-table row write (`02 27 <row> <little-endian int16 positions...>`) immediately queues low-stop homing, or FTMS reference homing for a connected bike reporting real resistance. The usual cadence check still applies. Startup homing preserves the active table and pending save, so BLE can continue receiving rows during homing. Full homing retains its existing table-reset behavior. Saving keeps the ten-second transfer delay and retries on failure. Further rows while the save is pending do not restart homing.

This characteristic also notifies when a shift is preformed or the button is pressed. 

See code for more references/info in BLE_Server.cpp starting on line 534

Hardware-version example:

- Client writes: `0x01, 0x2F`
- An ESP32-S3 board indicates: `0x80, 0x2F`, followed by the ASCII bytes for `Revision Three (ESP32-S3)`.
- Writes to `0x2F` return `cc_error` because the detected hardware revision is read-only.

All-settings snapshot (BLE or DirCon):

- Client writes `0x01, 0x31`. BLE clients subscribe to indications on the custom characteristic.
  A DirCon client receives the first chunk in the characteristic-write response and is automatically subscribed for the remaining chunks.
- The server serializes `userConfig->returnJSON()` once.
  Over BLE, it sends MTU-sized indications sequentially and waits for each acknowledgement before sending the next.
- Over DirCon, chunks use the same framing and arrive as characteristic notifications after the first write-response chunk.
- Every snapshot chunk begins with this seven-byte header:

| Offset | Size | Meaning |
|---|---|---|
| 0 | 1 | `cc_success` (`0x80`) |
| 1 | 1 | `BLE_allSettings` (`0x31`) |
| 2 | 1 | Snapshot framing version (`0x01`) |
| 3 | 2 | Zero-based chunk number, little-endian |
| 5 | 2 | Total chunk count, little-endian |
| 7 | remainder | UTF-8 JSON bytes |

The client validates that it received chunks `0` through `chunk count - 1`, concatenates the bytes after each header, and parses the result as JSON. If the connection closes or a chunk is missing, discard the partial snapshot and issue the read command again. Unknown JSON properties should be ignored so newly added settings remain backward compatible. The snapshot includes sensitive settings such as the Wi-Fi password, consistent with the existing individual password read command.

BLE requests and snapshot acknowledgments are queued for the maintenance task;
an ATT write completion does not mean the settings operation has completed. Wait
for the custom-characteristic response before sending the next request. A bounded
queue logs overflow and drops excess events. Disconnects invalidate queued work,
and a snapshot accepts acknowledgments only from its connection/session. Snapshot
transfers expire after five seconds without progress. The wire format is unchanged.

## Virtual gearing settings (firmware API)

Gear profiles are persisted on both targets and used for ratio-based stepper
shifting. Shift Amount sets the motor distance for the median positive ratio gap.
See [VirtualGearing.md](VirtualGearing.md). The experimental rider-weight ID 0x33
is retired and returns an unsupported/error response; it must not be reused.

### Gear tooth pairs (`0x34`)

Store each pair as `front * 100 + rear` in an unsigned LE16 (`5332` = 53x32).
Supply zero pairs for Unlimited (default), or 2–26 unique pairs. Both tooth
counts must be 1–99 and their rounded ratio must be 500–6000 in thousandths.
Firmware sorts by ratio, breaking ties by packed pair. Distinct pairs with equal
ratios remain separate gears with the same motor offset. The complete profile
is validated before replacement; invalid or truncated writes leave it unchanged.
Writing a tooth array also sets `gearPreset` to 0. While preset 1 is selected,
both metadata and indexed tooth reads return `FF 34` because it has no tooth pairs.

- Unlimited: write `02 34 00`; success/metadata response `80 34 00`. Indexed reads
  return `FF 34`. JSON stores `gearTeeth: []`; fixed Shift Amount spacing applies.
- Write: `02 34 <count u8> <pair0 LE16> ... <pairN LE16>`.
- Success: `80 34 <count>`. Failure: `FF 34`.
- Metadata read: `01 34`; response: `80 34 <count>`.
- Indexed read: `01 34 <zero-based index>`; response:
  `80 34 <count> <index> <pair LE16>`. Out-of-range indexes return `FF 34`.
- Changed-value notification: `80 34 <count>`, including edits that keep the
  count or ratios unchanged. Refresh indexed reads or the all-settings snapshot.
- A 26-gear write is 55 bytes, requiring ATT MTU **58 or larger** for a single
  normal BLE write. Reads, notifications and all-settings snapshots work at
  MTU 23. DirCon has no ATT limit.
- Example: `02 34 02 C7 14 D4 14` submits 53x19 and 53x32; success `80 34 02`.
  After sorting, reading index 0 with `01 34 00` returns `80 34 02 00 D4 14`.

After updating over BLE/DirCon, send the existing save command `02 18` to persist
it. Firmware-hosted web settings save automatically. Persistence and config
snapshots include `gearPreset` and `gearTeeth`; arbitrary ratio-only test profiles
are not supported.
In local simulation/inclination modes, `BLE_shifterPosition` uses **1-based**
gear numbers for bounded profiles and an unbounded signed shift count for
Unlimited (startup and successful homing select gear 8). Bounded profiles start
at one-third of their gear count, rounded down with a minimum of 1. Indexed pair
reads use **0-based** indexes. Bounded gear 1 is the zero shift offset; travel
limits still apply. No companion-app changes are included here.

### Named gear preset (`0x35`)

- Read: `01 35`; response `80 35 <preset LE16>`.
- Select Mixed Terrain 1x24: `02 35 01 00`; response `80 35 01 00`.
- Select Unlimited: `02 35 00 00`; response `80 35 00 00`. To select a bounded
  tooth profile instead, write its pairs through 0x34.
- Unknown preset IDs or invalid lengths return `FF 35` without changing the profile.
- Every profile change notifies `80 35 <preset LE16>`; tooth profiles also notify
  0x34 metadata. Reading value 0 alone does not distinguish Unlimited from a
  bounded tooth profile: read 0x34 as well.

Preset 1 persists as `gearPreset: 1` and `gearTeeth: []`. Its exact 24 ratios are
built into firmware; it reports one rear gear axis, starts at gear 8, and uses
the same median-gap Shift Amount mapping as tooth profiles. Save with `02 18`.

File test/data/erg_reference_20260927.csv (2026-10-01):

time_s | power_w | cadence_rpm | position_steps | command_steps | target_w | fit_power_w | fit_cadence_rpm | fit_target_w
0.0 | 23.0 | 78.0 | 7433.0 | 7433.0 | 0.0 | 17.0 | 79.0 | 0.0
1.003 | 22.0 | 77.0 | 7433.0 | 7433.0 | 0.0 | 23.0 | 78.0 | 0.0
2.009 | 28.0 | 76.0 | 7433.0 | 7433.0 | 0.0 | 22.0 | 77.0 | 0.0
3.009 | 26.0 | 76.0 | 7433.0 | 7433.0 | 0.0 | 28.0 | 76.0 | 0.0
4.011 | 32.0 | 77.0 | 7433.0 | 7433.0 | 0.0 | 26.0 | 76.0 | 0.0
5.025 | 37.0 | 78.0 | 7433.0 | 7433.0 | 0.0 | 32.0 | 77.0 | 0.0
6.034 | 37.0 | 78.0 | 7433.0 | 7433.0 | 0.0 | 37.0 | 78.0 | 0.0
7.04 | 30.0 | 79.0 | 7433.0 | 7433.0 | 0.0 | 30.0 | 79.0 | 0.0
8.048 | 33.0 | 80.0 | 7433.0 | 7433.0 | 0.0 | 33.0 | 80.0 | 0.0
9.051 | 28.0 | 80.0 | 7433.0 | 7433.0 | 0.0 | 28.0 | 80.0 | 0.0
10.053 | 31.0 | 80.0 | 7433.0 | 7433.0 | 0.0 | 31.0 | 80.0 | 0.0
11.054 | 24.0 | 80.0 | 7433.0 | 7433.0 | 0.0 | 24.0 | 80.0 | 0.0
12.062 | 28.0 | 79.0 | 7433.0 | 7433.0 | 0.0 | 28.0 | 79.0 | 0.0
13.066 | 27.0 | 79.0 | 7433.0 | 7433.0 | 0.0 | 27.0 | 79.0 | 0.0
14.069 | 30.0 | 80.0 | 7433.0 | 7433.0 | 0.0 | 27.0 | 79.0 | 0.0
15.072 | 30.0 | 80.0 | 7433.0 | 7433.0 | 0.0 | 30.0 | 80.0 | 0.0
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

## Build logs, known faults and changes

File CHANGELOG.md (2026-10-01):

# Changelog

All notable changes to this project will be documented in this file.

The format is based on [Keep a Changelog](https://keepachangelog.com/en/1.0.0/)
and this project adheres to [Semantic Versioning](https://semver.org/spec/v2.0.0.html).

## [Unreleased]

### Added

### Changed
- Restore thermal current limits and motor inhibition immediately when homing exits, including early returns and previously latched thermal/sensor faults.

### Hardware

## [26.9.15]

### Added
- Configurable ratio-based virtual gears with Unlimited, road, MTB, and gravel presets, persisted through web settings and the BLE/DirCon API.
- TMC2209 thermal protection and ESP32-S3 temperature-based motor current and radio power limits.

### Changed
- Calibrate FTMS resistance endpoints from confirmed interior transitions, with bounded retries, delayed/noisy feedback handling, and a motor hold after failed homing.
- Select the configured starting gear only after successful homing, preserve calibration progress messages, and keep rejected Unlimited shifts from returning after control-mode changes.
- Improve TMC UART setup/recovery and support long ESP-IDF linker-generator commands on Windows.

### Hardware

## [26.9.12]

### Added

### Changed
- Set classic ESP32 flash size to 4 MB in build defaults and release/debug configurations to match the existing partition table; retain 16 MB for ESP32-S3.
- Switch CI to pioarduino Core 6.1.19 and isolate compatible tool caches to prevent the SCons `FortranCommon` import failure.
- Update contributor and agent setup instructions to use pioarduino Core and its VS Code extension, including the shared CI version pin and platform-specific CLI lookup.
- Fix handling of 0 value in min and max brake watts settings so they persist correctly. Correct ERG shift behavior when max brake watts is set to unlimited (0).
- Increase homing timeout to 45s to accomodate bikes with longer resistance range.

### Hardware

## [26.9.5]

### Added

### Changed

### Hardware

## [26.9.5]

### Added

### Changed

### Hardware

## [26.8.23]

### Added

### Changed

### Hardware

## [26.8.21]

### Added
- Added new BLE firmware update protocol.
- Updated build script.

### Changed
- Truncate only the BLE-advertised device name when needed so the SmartSpin2k service UUID remains present in the legacy scan response.
- Keep ERG mode active and lower its target to the configured minimum brake watts when cadence falls below the ERG threshold.
- Prevent table-assisted ERG target changes from indefinitely blocking PID control when power approaches or settles near the new target.

### Hardware

## [26.8.14]

### Added

### Changed
- Start the maintenance task directly from `app_main()` and finish initialization on its configurable stack, preventing HTTPS firmware checks from overflowing the ESP-IDF main task.
- Consolidated board pin mappings, revision detection, current scaling, homing capability, and driver sense-resistor values in `boards.h`.
- Added a board-specific homing-sensitivity scaler, making the ESP32-S3 default equivalent to 80 while revisions one and two remain at 50.
- Moved stepper homing tuning constants into `settings.h`.
- Restyled the compact built-in recovery, OTA, and login pages and added visible feedback for image validation, upload failures, and reboot completion.
- Added S3-prefixed PlatformIO build artifacts and updated the release workflow to package them directly.
- Gzip HTML and CSS assets during LittleFS builds, serve them with the correct encoding, and make automatic filesystem updates binary-safe.
- Automatic filesystem updates now remove files outside the server manifest while preserving settings and power-table data, track the installed filesystem release version, and never replace it with an older release.
- Successful LittleFS uploads from the recovery page now reboot after acknowledging the upload so the replacement filesystem is mounted cleanly.
- Fixed gzip web responses being labeled with duplicate content-encoding headers, which Firefox rejected.
- Minor spelling fixes. 

### Hardware
- Corrected the ESP32-S3 shift-up and shift-down pin assignments.

## [26.7.15]

### Added
- Support for Spinning Bike Chrono

### Changed

### Hardware

## [26.5.27]

### Added

### Changed

### Hardware

## [26.5.4]

### Added

### Changed
- Adjusted BLE advertising to present SmartSpin2k as a cycling power sensor for improved Garmin discovery and pairing.
- Updated BLE setup to use a public device address for Garmin compatibility.
- added 15 minute timeout to blue status LED -  if not used, then it shuts off. 

### Hardware

## [25.12.11]

### Added

### Changed
 - links card update
## [26.5.2]

### Added
- Added CoolStep support for StealthChop stepper operation.

### Changed
- Improved StallGuard homing reliability with trimmed SG baseline sampling, threshold drift recovery, and stricter multi-tap end stop confirmation.
- Disable CoolStep during StallGuard homing to keep homing current behavior more consistent.

### Hardware

## [26.4.5]

### Added

### Changed

### Hardware

## [26.1.31]

### Added

### Changed

### Hardware

## [26.1.22]

### Added

### Changed

### Hardware
- Added Sole SB1200
- Batch reduced image sizes of reference photos. 

## [26.1.10]

### Added

### Changed
- Updated BLE scan results to include connected devices when using "ANY" wildcard.
- Added feed forward, disabled PowerTable for ERG lookup. 
- Added tests and removal of duplicates in pt column. 
- Added removal of negative numbers in pt table. 
- Refined ERG mode (stateful increase/decrease handling, smarter wait timers, improved PID logging).
- Adjusted FTMS resistance handling: ignore malformed IC Bike ranges, log raw range data, and skip IC Bike resistance samples.
- Rounded cadence/power calculations across CSC, CyclePower, Peloton, FTMS decoding; clamp invalid cadence values.
- Applied rounding for FTMS shift targets/resistance mapping and homing thresholds; use fabs in resistance model and paused duplicate cleanup.
- Fixed ERG mode logic to use correct watt increment and PID window for target calculation.
- Improved power table result validation during ERG mode transitions.
- Reset target incline to 1.0 when spinning stops in ERG mode.

### Hardware

## [25.12.28]

### Added

### Changed
- Removed >0 watts requirement to compute ERG.
- Filter cadence for crazy values. Only >0 && <250 now accepted.
- Filter watts for crazy values. Only >0 && <3000 now accepted. 
- Fixed bug where scans may not happen even when configured devices aren't connected.  
- Worked with Mark Roy to tune PID.
- Added proper rounding from float to int for power and cadence.
- More ERG tweaks for Marc Roy. 
- If homed, we throw out negative PowerTable returns. 
- After startup homing, set gear 8.

### Hardware

## [25.12.17]

### Added

### Changed
 - Links card update.
 - Removed indications from Control Point Characteristic to make Zwift on Android happy. 
 - IC4 reported HR won't override other HRM.
 - Improved ERG response for homed tables.
 - Slightly faster Peloton bike + homing.

### Hardware

## [25.11.21]

### Added

### Changed
- Make Zwift happy during spin down by sending "stop pedaling" every 1 second.
- Added power scalers for stepper hold and homing.
- Updated driver settings for improved stall detection.
- FTMS bikes will now home using reported resistance if available.  

### Hardware

## [25.11.19]

### Added

### Changed

### Hardware

## [25.11.4]

### Added

### Changed
- Added support for reading resistance range from connected FTMS devices
- Improved resistance mode control logic for bikes with and without native resistance reporting
- Fixed resistance value parsing to correctly handle 16-bit values
- Reduced default max brake watts from 1400w to 1000w. 

### Hardware

## [25.10.19]

### Added
## [25.11.3]

### Added

### Changed

### Hardware

## [25.10.19]

### Added
- Added Rouvy Dircon. Working! 

### Changed
- Fixed Rouvy Connection 25-10-18 caused.
- Updated build scripts. 

### Hardware
- Added Merach.

## [25.9.30]

### Added

### Changed

### Hardware

## [25.9.8]

### Added

### Changed
- WiFi will automatically switch/reset if needed after firmware update. 
- BLE advertisement data reworked and optimized. 

### Hardware

## [25.8.26]

### Added

### Changed

### Hardware

## [25.9.17]

### Added

### Changed
- Fixed incline mode handling negative numbers. 

### Hardware

## [25.9.8]

### Added

### Changed
- Only check battery level on initial connection. This is to fix Tempo power meter drops. 
- Moved battery information to the SpinBLEAdvertisedDevice class.
- When adding to SpinBLEAdvertisedDevice, check adevname as well as address to prevent duplicates.
- Stopped reusing BLE clients for better connection reliability.  

### Hardware

## [25.8.26]

### Added

### Changed
- Unique (static) name generation for Android devices to prevent re-pairing issues.

### Hardware

## [25.8.26]

### Added

### Changed

### Hardware

## [25.8.26]

### Added

### Changed

### Hardware

## [25.8.18]

### Added

### Changed
- Added better BLE device logging, even when a connection isn't made.
- Fixed Echelon connections. 

### Hardware

## [25.8.16]

### Added

### Changed

### Hardware

## [25.8.3]

### Added

### Changed
- Fixed rare crash due to calling new scan before the previous onScanEnd callback was complete. 
- Removed serial printf's during updates as it was causing occasional update issues.

### Hardware

## [25.8.3]

### Added

### Changed

### Hardware

## [25.7.30]

### Added

### Changed

### Hardware

## [25.7.29]

### Added
- Added state machine for shifters allowing faster and more reliable shifting. 

### Changed
- Removed unused file. 
- Added license to test files.
- Fixed unterminated comment.
- Fixed BLE and WiFI updates.
- Improving use of pTab4Pwr.
- Fixed edge cases of pTab4Pwr causing runaways.
- Reduced the power output when no power table.
- Fixed Dircon with Mywoosh.
- Fixed Bug with Peloton data being requested too often. 
- Fixed Bug with Dircon data being sent too often. 
- Fixed Bug with BLE TX/RX being overwhelmed by the above two. 
- Homing now takes multiple samples at the start of the run. 

### Hardware

## [25.5.31]

### Added
-Root CA certificates are now updated automatically during every build.

### Changed

- Added CSC sensor selection in BLE Scanner html.
- Turned moving neighbors into a function, moved cubicspline class to power_table.h, merged dircon2, and changed added set_points changes

### Fixed
- Fixed stack smashing protection failure in SpinBLEAdvertisedDevice::enqueueData by adding a buffer size check to prevent overflow when handling BLE notifications larger than the buffer size

### Hardware

## [25.3.13]

### Added

### Changed
- Multiple html and css improvements. 
- Lookup uses existing interpolate and extrapolate functions. 
### Hardware

## [25.1.28]

### Hardware

## [25.4.8]

### Added

### Changed
- PID loop for ERG mode instead of P loop.
- Fixed flags in CPS and CSC which were causing issues in GTA Bike. Thanks @matthewsshirley !
- updated cert.h

### Hardware

## [25.1.28]

### Added

### Changed

### Hardware
- Updated IC SE Insert to fit better.
- Added Schwinn AC bike insert and mount.

## [25.1.19]

### Added

### Changed
- Bugfix in ERG Mode
- Bugfix for spamming log messages when using Peloton and not homed. 

### Hardware

## [25.1.12]

### Added

### Changed
- All New HTML Files!

### Hardware

## [25.1.10]

### Added

### Changed
- Added checks for IC SE Bike Connection. 

### Hardware

## [24.12.8]

### Added

### Changed

### Hardware
- Added Dmasun bike
- Added Equinox Soul Cycle
- Added Sole SB700
- added bike mount for Joroto X2 and any other bike with hex shape front tube
- replaced old inserts for Joroto X2 with new 60.5

## [24.12.7]

### Added

### Changed
- Fixes homing not being removed after powertable reset.
- Shifting will always abort homing, even if homing hasn't been preformed yet. 

### Hardware

## [24.11.25]

### Added

### Changed

### Hardware
- Added rubber band holder to Peloton mount.
- Decreased Peloton insert size slightly. 
- Added rubber band holder to IC4/C6 mount.
- Added Sunny B1805 Bike. 

## [24.11.16]

### Added

### Changed

### Hardware
- Decreased tolerances around bearings and gears.

## [24.11.10]

### Added

### Changed
- Multiple Homing refinements.
- Working with resistance mode on QZ & Peloton
- PowerTable Import via Custom Characteristic fixed. 
- Check for cadence (before homing) so that we don't home when nobody is around.
- Don't depower the stepper if there is cadence. 

### Hardware
- Added Sunny B1805 insert. 

## [24.11.7]

### Added

### Changed
- Homing refinements.
- Resistance shifting improvement.
- Reduced Peloton logging to 1/sec.

### Hardware

## [24.11.5]

### Added
- Knob homing if calibrate trainer is selected in an app.

### Changed
- Added backing off of the stop before we test to prevent runaway grinding during homing. 
- User can abort homing by pressing shifter. 

### Hardware

## [24.10.30]

### Added

- Added pass through shifting in both ERG and SIM mode.
- Refined and added BLE custom characteristics for upcoming configuration app.
- Added CSC Service to BLE server.
- Added Yosuda-007C.
- Updated wiki banner.
- Added automatic update of Changelog sections on pull request to develop. 
- Added support for the Zwift gear display.

### Changed

- Amend always option to git describe.
- Updated communications overview picture.
- Updated kit purchasing links.
- MIN_ERG_CADENCE created and changed from 20 to 30.
- Fixed DNS server in AP mode.
- Fixed an issue with IC4 and variants not displaying device name in Bluetooth scanner. Fixes #500.
- Switched from using Power Table to a Torque Table for better compensation in cad variations.
- added test for invalid Peloton data to keep stepper from running away without resistance information.
- Fixed a bug with Trainer Day and rapid ERG sending.
- Many updates and bug fixes which enable the Config App to communicate with SmartSpin2k.
- Scanned devices no longer saved to filesystem. The new scanning method would keep snowballing them otherwise.
- increased MTU for android.
- Updated WiFi connection setup.
- Firmware no longer updates if only the html files need to be loaded.
- BLE scans blocked during firmware upgrade.
- Increased the default incline multiplier to 5.
- Added more robust activity monitoring and reboot every 30 minutes if there is no activity.
- Updated all references of SmartSkin2K to SmartSpin2k for consistency.
- Fixed bug where BT scanner "Loading" wouldn't disappear if "NONE" and "NONE" were selected.
- Fixed Bug where ERG setpoint state wasn't going to the positive control loop correctly.
- updated arm length readme for JLL IC400
- Added yokeWidth table to bike mount readme for bikes that use the OpenSCAD yoke.
- improved OpenSCAD for yoke to add roundness to the curve.
- Refactored BLE_Server into separate files for each BLE Service.
- Fixed bug in CPS service for Wahoo app (and probably others).
- Depreciated the SPIFFS->LittleFS upgrader.
- Increased ERG mode sensitivity.
- Removed extra logging when loading table.
- Prevent table returns from going in the wrong direction.
- Fixed bug with stepper speed not updating.
- Removed driver temp checking. It's not accurate on the ESP32.
- Peloton resistance limit enhancements.
- Continue updating power metrics to other clients if one client disconnects.
- Freed 19k of ram by consolidating tasks and using timers instead of delays.
- Updated baud rate to 115200 to ensure compatibility with other ESP32 variants.
- Added a final test to check if ERG mode has commanded a move in the proper direction.
- Aligned the values between the config app and web interface.
- Added ability to send target watts through the custom characteristic. 
- Added a final test to check if ERG mode has commanded a move in the proper direction.
- Cleaned up targetPosition to make it easier to understand. 

### Hardware

- added Yesoul S3.
- Wire diameter reduced from 7.2mm to 6.0mm on the window passthrough to accommodate the latest batch of cables.
- Changed reference to M4 bolt to M5 Bolt in the construction instructions pdf.
- Increased right side case mounting hole to 5.5mm so the bolt slides in easier.
- Added Pooboo and York SB300 Bikes.
- Increased size of the arm hardware holes by .25mm.
- Added Spinning L7 bike.
- Added Yosuda bike.
- Added Peloton low profile (for slammed bars) bike mount by @chaloney
- Updated CAD for the case to work flawlessly with small tweaks to motor height.
- Removed some free play in the IC4 insert.
- Added IC Bike SE
- Removed some free play in the IC4 insert.
- Added Bowflex Velocore bike.
- Added another Y cable picture for Peloton.
- Moved wire guard up 1 mm.
- Added JLL-IC400.
- Tightened up tolerances on the case.
- Increased gear spacing by .1mm
- Reduced bearing clearance by .15mm
- Added Stryde Bike.
- Added Life Fitness ICG8.

## [23.6.28]

### Added

- new photos for wiki
- Added battery monitoring of BLE devices by @Flo100. Implemented BLE HID shifting.
- Added table for arm lengths.

### Changed

- Disregard Peloton serial power and cadence if user has a BLE power Meter selected.
- Filesystem no longer updates when auto-update is unchecked.
- Holding shifter buttons on boot now erases LittleFS as well as resetting settings.
- Fixed bug where "none" hr still scanned. Credit to @xpectnil for discovering.
- Simplified Platform Packages to work better with newest version of PlatformIO.
- Fixed broken images in wiki.
- Valid files displayed on OTA page.
- Increased heap for more reliable OTA updates.

### Hardware

- Tweaks to IC4 bike mount
- directory cleanup
- tweaks to echelon bike mount
- Revised an old shifter cover for more options.
- Updated arm folder to procedurally generated arms ov various lengths.
- Updated C7 bike mount to use hook style arms.
- Updated PCB switch placement.
- Updated PCB Inductor.
- Updated PCB Motor Connector.
- Updated PCB Back Side Silkscreen Layer.
- Added fixed length arms.
- Added R3 assembly instructions.
- Added back a modified version of the single button shifter.
- Changed Logo font and position.
- Increased material around the top screw hole.
- Made shifter plugs slightly smaller.
- Increased diameter of shifter strain relief.

## [23.1.22]

### Added

- Added blocking for shifts above or below min/max setpoints.
- Added Peloton serial decoder to sensor factory.
- Added blocking for shifts above or below min/max set points.
- Added power scaler for new board.
- Added Main Index link to develop.html.
- Added feature to automatically reconnect BLE devices if both are specified.
- Added ftms passthrough. FTMS messages from the client app are now passed to a connected FTMS device.
- Added resistance capture to Echelon.
- Added Resistance capture to Flywheel.
- Added Resistance Capture to Peloton.
- Added Resistance capture to FTMS.
- Added scanning when devices are not connected.
- Added ability to set travel limits based on resistance feedback from a bike.
- Added shifting in ERG mode (changes watt target).
- Added shifting in resistance mode (changes resistance target.)

### Changed

- PowerTable values are now adjusted to 90 RPM cad on input.
- PowerTable entries are now validated against previous entries.
- Changes to default settings for better ride-ability. Raised incline multiplier and erg sensitivity, increased incline multiplier and max brake watts.
- Fixed a bug in the new cadence compensation where an int should have been a float.
- Fixed broken pre-commit on my local dev machine.
- Moved serial checking to own function.
- Reduced verbosity of ERG logging.
- Fixed instance of BLE PM dropdown not being saved correctly.
- Moved post connect handling to the ble communication loop. (improves startup stability)
- Fixed bug submitted by @flo100 where MIN_WATTS in ERG should have been userConfig.getMinWatts();
- FTMS resistance mode now changes the attached bike resistance with feedback. (i.e. setting resistance to 50 with a Peloton attached will set 50 on the Peloton)
- Refactored rtConfig to use more measurement class.
- Increased stepper speed when a Peloton is connected. (very light resistance)
- Updated libraries to latest

### Hardware

- Removed duplicate directory in direct mount folder.
- New case for the new PCB :)
- Revised directory structure in /hardware
- updated Bowflex C7 mount for improved usability
- updated Echelon knob insert for durability
- Peloton bike mount updated for improved usability

## [22.10.8]

### Added

- Automatic build script for github.
- Added dependabot.yml
- Added changelog merge automation.
- Added StreamFit
- Added developer tools html.
- Added automatic board revision detection.
- Added THROTTLE_TEMP to settings.h. The internal ESP32 temperature at which to reduce driver current.

### Changed

- Fixed a few compile issues for case sensitive operating systems.
- Release is now the default build option.
- New release is automatically created on pull request merge.
- Fixed HR in the hidden btsimulator.html
- Enabled CORS for doudar/StreamFit.
- Re-arranged index.html.
- restored link to bluetooth scanner.
- Reverted conditional variable initialization in powertable lookup function.
- Simplified cadence compensation in powertable lookup.
- Fixed issue where you couldn't set a ERG target less than 50W (MIN_WATTS wasn't being respected.)
- Increased the BLE active scan window.
- BLE scan page now shows previous scan results.
- BLE scan page duplicates bug fixed.
- BLE scan page dropdowns default to devices found during scan.
- Increased THROTTLE_TEMP from 72c to 85c.

### Hardware

- Ultra Short Direct Mount case for use on bikes with limited space between knob and head tube
- Direct mount and arm for Bowflex C7 - for use with Ultra Short Direct Mount

### Hardware

- Minor improvements to tolerances for direct mount mod
- created peloton-specific arm for direct mount use. IC4 model is usable, but a bit short.
- modified short case to include chamfers and fillets at the screw posts to improve thin wall printability in superslicer
- beefier arm for direct mount
- NEW: Direct Mount short case for bikes with reduced clearance in front of knob.
- NEW: Bolt through short case for direct mount use with Generic Bike http://smile.amazon.com/gp/product/B07S3YWSNM
- NEW: Direct mount for Life Fitness IC7

### Hardware

- Added new case design for upcoming integraded SMT PCB.
- Added Initial KiCAD PCB Commit.

## [2.7.9]

### Added

- Added comment when files are written to LittleFS.
- Added comment when firmware starts to update.
- Added setting for minWatts.
- Can now update LittleFS via update page.
- Removed dependency on jQuery. (Saves 30k in filesystem)

### Changed

- Driver Over Temp logging fixed.
- Updated Libraries to newest versions.
- Disabled setting of min/maxWatts if minWatts/maxWatts is 0.
- Added a check to workaround a bug where a powertable pair member was zero.
- Fixed a bug where a powertable pair could be returned that was larger than the powertable size.
- Changes to default settings.
- Fixed scanning memory leak.
- Scans continuously unless all devices are connected or set "none"

### Hardware

## [2.6.26]

### Added

- Added functions for automatic settings conversion from SPIFFS
-

### Changed

- updated CA for OTA updates
- Converted filesystem from SPIFFS to LittleFS
- Fixed endianness for ftmsPowerRange and ftmsPowerRange.

### Hardware

- added chamfer to screw posts in case body (direct mount mod)
- minor tweak to shifter cable retainer.

## [2.2.8]

### Added

- Added screenshot for wiki main page
- Added functions to start and stop WiFi and Http server.
- Added Additional logging to the custom characteristic.
- Added option to enable/disable UDP logging. Default is disabled.
- Added Wiki links to most SS2K pages. [see #314](https://github.com/doudar/SmartSpin2k/issues/314)
- Added WebSockets for logging [see #173](https://github.com/doudar/SmartSpin2k/issues/173)
- Reworked logging to run log-appender outside the worker task (task no longer blocked by logger traffic).
- WebsocketsAppender can handle multiple (up to 4) clients. Status.html will reconnect if connection to websockets server is disconnected.

### Changed

- Refactored ERG.
- Reset to Default must be confirmed [see #51](https://github.com/doudar/SmartSpin2k/issues/51)
- Update Firmware: Upload dialog accepts .bin, .html and .css files. [see #98](https://github.com/doudar/SmartSpin2k/issues/98)
- Removed conflicting secondary BLE indicate when a shift was preformed via the custom characteristic.
- Default stepper power is now used on reset to defaults.
- Refactored Main and HTTP Server.
- Changed from hard coding to Enums in BLEServer.
- Added simulateWatts to ERG mode internal check.
- Increased BLE Stack(s) and reduced ERG stack.
- Disabled shifter ISR while ERG is running.
- Fixed possible infinite loop in ERG when stepper never reached target position due to being past min or max position.
- When UDP logging is enabled, html will no longer request logging info.
- Increased remote server minimum packet delay to 325ms and max to 700ms.
- Updated Arduino_esp32 to the latest 2.0.2 version.
- Fixed all libraries to static releases.
- Reduced max_connect_retries from 10 to 3.
- Increased max_scan_retries from 1 to 2.
- Now only send notifications for subscribed characteristics.
- Increased JSON size for userConfig (hopefully fix config saving issues).
- Changed LOGE messages in spiffs logging to regular LOG messages so they will display via network logging.
- Complete BLE Client connection code rebase.

### Fixed

- bluetoothscanner.html now lists fitness machine services in the PM list.
- Fixed bug in external control.

### Hardware

- Added Ultra Short Case mod which should allow as little as ~40mm from knob center to head tube.
- Revised shifter for easier printing. Updated printing instructions.
- moved original shifter design into Archive directory

#### Direct mount Mod

- IC4 Mod renamed to Direct Mount Mod. Several directories have changed.
- bike mount and arm added for Echelon Connect Sport
- Arm design revised for added stiffness
- Case, arm and bike mount separated into individual CAD files for easier edits.
- Arm and bike mount re-drawn in CAD. It should be much easier to create designs for new bikes now.
- Added direct mount for Revmaster and Peloton bikes
- New insert for Startrac

## [1.12.30]

### Added

- Added userConfig shifterDir to change direction of shifters in software to compensate for wiring
- Added userConfig StepperDir to change direction of stepper in software to compensate for wiring
- Added backend and html for shifter and stepper directions.
- Added parameters for auto homing.

### Changed

- Fixed a couple bugs in PowerTables
- Fixed BLE Scanner webpage not displaying devices.
- Corrected a check in the FTMS write control point indication.
- readme copy change
- added bridging improvements for screw holes - in cad but missing in STL

### Hardware

-

#### IC4 Mod

-

## [1.12.26]

### Added

- Added Webpage for Shifting.
- Added /shift server on backend.
- Split userConfig into userConfig and rtConfig.
- Added ERG testing to btsimulator.html
- Broke out ERG computation into it's own task.
- Added image for wiki.
- Replaced existing shifter housing with new and improved 2 in 1 revision

### Changed

- Adjusted the order of "Submit" "Reboot" and "Reset to Defaults" on the settings page.
- Adjusted the setting webpage so "reset to defaults" is harder to accidentally press.
- Increased the amount of free stack by removing the default Arduino loop();
- Updated /shift server on to rtConfig.
- Fixed redeclaring global targetposition in moveStepper().
- Renamed Settings page "Submit" button to "Save Setting"

### Hardware

- Increased hex head and nut size to 13mm.
- Increased depth on Knob Cup 2mm so a thicker nut can be used.
- Added assembly .gif images.

#### IC4 Mod

- NEW: Hex bolt mod for 40t gear and matching ic4 cup/mount. This is a drop-in replacement for the plastic printed gear + cup/holder combination. This adds a lot of strength
- Renamed directory to something more apparent.
- Removed need for support material from case.
- Thicker slide design which removes need for washers.
- Slightly shorter slide - should allow more flexibility for ss2k placement on IC4.
- Tighter tolerances on case and bike mount for slide fitting. It should be a tight enough to prevent accidental removal
- Slightly larger diameter holes for m3 screws used in case assembly. Screws should be much easier to insert
- Additional tolerance for m5 fitting.
- Combined knob cup & knob insert for schwinn to reduce amount of plastic needed for the schwinn.
- Including a revised 11t stl - A bit more clearance on inner diameter the drive shaft on my steppers.

## [1.12.2]

### Added

- Firmware update will now download only spiffs files if missing without updating the firmware.
- New UDP logger by @MarkusSchneider .
- Added custom IC4 build and mount by @eMadman .

### BugFixes

- Power Correction factor now minimum .5 maximum 2.5 and added checks to stay within limits.
- 404 now redirects to index file handler.
- settings_processor now checks shiftsteps field to determine if it's on the main settings page.

## [1.11.24]

### Added

- Moved FTMS callback decoding outside of the callback.
- Revamped the way notify buffer works as it was causing a memory leak.
- BLE Custom Characteristic motor driver calls now apply settings received.
- Motor current now automatically scales if ESP32 temp starts getting too high.
- Added comments after compiler #endif Statements to make it easier to see what the partner #if statement is.
- Added BLE_syncMode to support syncing shifterPosition with bikes that also report their resistance level.
- Added git tag to prevent branch from downgrading to the last release.
- Added Hardware Version 2.0.
- MCWPWM for stepper control.
- Erg Sensitivity control added.
- Function to stop motor and release tension if the user stops pedaling in ERG mode.
- Received BLE is now buffered and then processed.
- Added Fitness Machine supported inclination range characteristic.
- Additional unit tests.

### Changed

- Renamed BLE_stepperPosition to BLE_targetPosition to clarify the variable it controls.
- Increased BLE communications task to 3500 stack.
- Fixed recurring debugging line when driver was at normal temp.
- Fixed length of returnValue on custom BLE bool read requests.

## [1.6.19] - 2021-6-19

### Added

- Initial implementation of the custom characteristic.
- Added additional FTMS characteristics and some refactoring of shared variables
- Added GZipped jQuery to fix non WAN connected manual updates.
- Pin arduino-esp32 package to version 1.0.6 to fix build issue
- Added + - Buttons to sliders.
- Added firmware checklist to "~/" for PR and release candidate testing.
- Added README.md to "~/Hardware/\*" that provides help for the files contained within.
- Added BakerEchelonStrap to "~/Hardware/Mounts/".
- Added positive retention clip to "~/Hardware/Mounts".
- Added Logan clip to "~/Hardware/Mounts".
- Added experimental rigid mounting strap. \* Fixed width to 65mm.
- Add images for video links in Wiki Build How To.
- Added webhook for simulated cadence.
- Add image for video link in Build How To
- Added images for video links in Wiki Build How To
- Added XL (Extra Long) Mounting strap for Echelon.
- Added Insert Peloton 7 Flat V2 .sldpart and .stl.
- Added initial credits file.
- Added initial changelog.
- Enabled cpp-lint, pio check, and clang-format to enforce coding standards and catch errors.
- Added support for ruing pre-commit to run pre-push checks.
- Added github workflow on pull_request to validate changelog and coding standards.
- Add hyphens to Flywheel GATT UUIDs.
- Filter Flywheel advertisements by name.
- Added unit tests for CyclePowerData.cpp
- Add documentation to SensorData class.
- Enabled native testing.
- Added logging library which supports levels.

### Changed

- Moved Vin to the correct side on the ESP32 connection diagram.
- Power Correction Factor minimum value is now .5
- Made Revmaster insert slightly smaller.
- Fixed minor spulling errurs.
- Reorganized hardware library into per part subfolders.
- Updater shifter cover to version 9.
- Fixed missing strap loops on non-pcb case.
- Power Correction Factor slider now updates correctly.
- Removed unused http onServer calls.
- Repaired btsimulator.html
- Shortened HR characteristic to 2 bytes (Polar OH1 format)
- Increased ShiftStep UI slider range.
- Replaced DoublePower setting with PowerCorrectionFactor setting.
- Reverted bytes_to_u16 macro.
- Erg mode tweak.
- Added another test for Flywheel BLE name.
- Updated Echelon Insert
- Fixed many issues exposed by the addition of cpp-lint, pio check, and clang-format.
- Fixed merge issues.
- Fixed Echelon licenses.
- Fix Flywheel power/cadence decoding.
- Ignore zero heart rate reported from remote FTMS.
- Fix Assimoa Uno stuck cadence.
- Started extract non-arduino code into a cross-platform library.
- Changed all logging calls to new logging library.

### Removed

- Deleted and ignored .pio folder which had been mistakenly committed.

\*1.3.21

- SS2K BLE Server now accepts more than one simultaneous connection (you can not connect SS2K to both Zwift and another app simultaneously)
- Echelon bike is now supported
- SmartSpin2k.local more accessible with different browsers (fixed certain MDNS dropouts)
- Flywheel bike support built in (still untested)
- Backend (client) completely revamped to allow more device decoders, better stability, and faster network speeds.
- Lots of FTMS server and client polishing
- Added testing for decoders
- Versioning now comes from releases
- NimBLE library included
- Increased total max connections to 6 devices
- Refined debugging logs

\*1.2.15

- Fixed BLE cadence when accumulated torque values are present
- Lowered memory footprint

\*1.2.6

- Added limited Telegram BLE debugging information for development. No sensitive information is sent back. I can make this telegram info available as a private group (in Telegram) if anyone is interested in seeing it. This was added because there are a couple BLE devices that don't seem to conform to the standard protocol and we need more information about them to get them to work properly.
- Internal web UI links now use IP address instead of the local DNS name for compatibility with certain routers.
- Added a favorite icon (favicon.ico) for browser compatibility.
- Fixed an BLE bug which would occasionally cause a crash on scanning.
- Changed priority of subroutines and optimized task memory footprint.
- Streamlined the WiFi connect sequence.

\*0.1.1.22

- Power meter will now switch to the most recently connected and disconnect the other.
- Double power option in the Bluetooth scanner webpage.
- Bluetooth scanning now happens via a flag set in the client task.
- Backend of the Bluetooth scanning page revamped.
- Removed dedicated HTTP server callback for the Bluetooth scanner.

\*0.1.1.11

- All metrics now zero when correct BLE !connected.
- Added HR->PWR off/auto switch.
- WiFi starts up faster.
- BLE now connects device on save.
- BLE Scans are less error prone.
- MDNS Fix for certain android browsers.
- and probably lots of other stuff.

\*0.1.1.2 A new binary version is out in OTAUpdates. Units should automatically update to this newest version.

- Changes:
- WiFi Fallback to AP mode is now 10 seconds.
- WiFi AP mode Fallback SSID is now device name (MDNS name), and the password is whatever you have set.
- ERG Mode slightly more aggressive.
- StealthChop 2 now selectable in settings.
- Holding both shifters at boot resets the unit to defaults and erases filesystem. (firmware remains intact)
- Holding both shifters for 3 seconds after boot preforms a BLE device scan/reconnect.

- Bugfixes:
- Automatic Updates setting switch now works :

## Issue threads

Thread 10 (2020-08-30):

Setup Stepper Enable Pin

doudar, 2020-08-30:
Currently we have the enable pin directly soldered on the stepper driver. Since the stepper is in a tiny enclosed space it would be best if we add another wire from the esp32 to the stepper driver to use the enable pin so that the stepper isn't using current to hold the position (the spin bike knob doesn't need to be actively held anyway).

1 We need to setup this pin in the code

2 Add the logic to the stepper driver function

3 update the wiring diagram

4 do a hardware test

doudar, 2020-09-12:
Hardware test completed

Closed 2020-09-12.

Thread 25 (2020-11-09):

Carrier PCB and crank

kswiorek, 2020-11-09:
I could design a carrier PCB for the three componets, that would fit in this space:
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
You don't have to use a buck converter for that, just a small power regulator is enough as the ESP doesn't take much power.
I dont have the exact same ESP module, so I could either use mine, wait a month untill it arrives from China, or you could send me the distance between the headers on yours.

I could also provide code and the documentation for a DIY crank power meter. I also have a version that emulates the power meter directly on the crank, so it would be able pair with yours.

doudar, 2020-11-09:
I'm taking a bunch of measurements in F360 right now to figure out what orientation may work. I'll get back to you very shortly.

doudar, 2020-11-09:
Alright! I'm back! Thank you for taking a look btw!!!

I looked at putting a PCB into the top cover and maybe it could be done but the stepper motor nearly touches the cover, so there isn't much space. With a very small amount of rearranging, it could be possible however:
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

The biggest issue I see with this is that access to the boot button (shouldn't be needed but occasionally still is) might become complicated because I don't see a way of doing this without making a "PCB sandwich" with the boards attached to pin headers on opposite sides of the PCB like this:
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

So after careful consideration, I think it might be best to keep the esp32 in it's current location and just add stack onto the back side with the PCB containing headers on each side and the power supply on the lower half of the board. The upper half (nearest the usb interface on the esp32 should be where the stepper driver mounts, otherwise the shroud for the gear case may interfere with the heat sink on the stepper driver.
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

There's currently about 40mm from the back side of the ESP32 to the side of the stepper motor, and the full stack I'm estimating at around 36mm.

Another consideration if we decide to make a custom PCB, is that I'd really like to add serial support for the TMC2225, so a PCB should probably contain the those traces. I haven't done much research into what exactly is required here, but being able to adjust the driver amperage via software and/or detect stalls and travel limits would be invaluable on the software feature side of things so it cannot be ignored.

Good Luck!!!! Let me know

kswiorek, 2020-11-09:
Could you give the whole cad assembly with the motor and board? I haven't found it in the repository.
I have some experience with TMC2130 - they use SPI, but are otherwise simmilar.

kswiorek, 2020-11-09:
The whole stack is quite thin - i don't use the normal headers:
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

doudar, 2020-11-09:
I'm waiting on the F360 export. It's taking a while.

In the mean time, here's the info for the driver:
https://github.com/bigtreetech/BIGTREETECH-TMC2225-V1.0/blob/master/TMC2225%20V1.0%20manual.pdf

I have no issues sending some esp32's your way if you're committed to helping with this. I'd just need your address.

kswiorek, 2020-11-09:
I don't think international shipping would make sense. I found that I can order these boards locally so I will probably do that. I have an idea how to make it, so I will just design it and show you.

doudar, 2020-11-09:
The assembly is uploaded. If your idea only takes up a few mm I'm open to raising the recess in the cover a bit. I'd prefer to keep it to an absolute minimum though because it already impedes being able to lower the handlebar stem completely on certain bikes.

doudar, 2020-11-09:
But your idea does look very thin! Awesome!

kswiorek, 2020-11-16:
[Smart_trainer.zip](https://github.com/doudar/SmartSpin2k-PlatformIO/files/5547010/Smart_trainer.zip)
Ok, finally. After about an hour messing around with fusion I designed the PCBs. They weren't tested and they shoud fit, but I didn't manage to combine them with the assembly.
One board uses the A4988, the other a TMC2130, because I didn't know how to set the TMC2225 up. The TMC2130 has a nice library with software SPI.
This whole thing fits inside the "Tall_Cover" and could be made to hold with some latches, but I don't have the means to make the edge repeatably, so it needs to be tested with a milled PCB
I will try to test the electronics soon, but if I didnt make any mistakes with the order of pins, it should work.

doudar, 2020-11-16:
Thank you - I haven't looked yet, but I included them in the hardware/PCB folder.

I'll see if I can pull these into Fusion to make sure they fit and then if so, I'll try to get some made.

The only reason I have the 2225 is that they are/were cheaper than the 2130 and they seem to work well. I *think* the pinout is the same and they may be compatible with the library, but I haven't messed around with either yet. The 2225 is single wire UART whereas the 2230 is SPI. I'm not really sure what the difference is as I thought SPI was basically single wire UART...  I guess I'll do some research!

Don't hesitate to ask if you have any issues/questions if you build my project. While I've made a bunch of prototypes, I don't think anyone else has built it yet. (It hasn't been public long). I am fairly confident on it being robust - I've got probably 15 hours of regular (non-testing) riding with it and countless hours testing.

Thanks for your contribution!

kswiorek, 2020-11-16:
It's worse :) the other one is flipped. The power supply pins should be near the edge, so the usb can be used from outside

kswiorek, 2020-11-16:
[universal.zip](https://github.com/doudar/SmartSpin2k-PlatformIO/files/5549113/universal.zip)
Ok, now I created a universal board that connects all the possible setup pins to the ESP (there is a lot GPIO left) and moved the buttons to the other side. You can delete the old PCBs with the mistake

This PCB is designed with quite large tolerances, so it's possible to make it at home with a laser printer

doudar, 2020-11-25:
Thank you very much for your contribution. It taught me how to walk through the PCB design process in Eagle, which I hadn't done before.

I ended up redesigning this to fit on the ESP32 mount on the side of the case because I couldn't come close to fitting it once the heat sinks were on the modules. I also think this position is a little better for heat dissipation and inevitable sweat ingress.

I mostly kept your original schematic but I did have to change a couple things. The shifters are pull_up for less issues with bouncing & EMI. My software debounce also seems to be pretty robust, so I was able to get rid of the debounce caps. I also added some filtering to the 7805 because I'm guessing the stepper driver is making some pretty big ripples.

I've since had a limited run fab'd (dang that's cheap nowadays!) and they are pretty good. Worked on the first try!

I do plan on making a couple more changes however. I haven't measured it, but the current draw on the ESP32 must be fairly high because the 7805 is getting too hot to touch. I could heat sink it, but since I'd like to try to stay with passive cooling, I'm going to try some TO-220 form factor switching power supplies. (RECOM R-78E5.0-0.5) https://bit.ly/3m87KPc

I also am unsure if I should keep the 5v and then power both modules directly with 5v, or switch the power supply out to a 3.3v model (to bypass using the 3.3v regulator on the ESP devkit. My first prototype with the PCB is putting out much less torque than before, but there were other variables changed (serial controlled amperage and other settings) on top of switching from 5v to the 3.3 off the ESP32.

Anyway, lots of rambling. hopefully some of it is coherent.

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

kswiorek, 2020-11-26:
That's nice! The 3.3V regulator would probably help. I didn't even think of that, because my design has to have 5V for the LCD. I'm using just this single regulator and it gets hot - by feel I'm guessing about 80°C, but the maximum rating is 125°C, so it probably won't be a problem.

doudar, 2020-11-26:
I did some testing and powering the driver directly with 5v doesn't make any difference. Everything seems to be operating the same either way. I'm able to get plenty of torque by setting driver rms current to 2000 (which seems very high) where my other serial prototype (non-pcb) subjectively puts out the same torque at roughly half that setting.

It could be this specific driver, or it could be that I changed something via serial that I shouldn't have on the driver (shiny new settings, so I had to mess with them all ;) )

doudar, 2020-11-29:
New PCB is working great as well as the DC switching power Supply. Marking this closed!

Closed 2020-11-29.

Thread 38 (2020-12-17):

PCB design iteration #2

doudar, 2020-12-17:
1'st issue is that since the linear regulators get too warm, I've switched to:
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
Recom R-78E5.0-0.5 for power regulation. It's slightly bigger than the LM2905, so items around it need to be spaced out just a tad bit.

doudar, 2020-12-17:
2'nd issue is that the holes in the corners are too small to pass the mounting screws through to the ESP32. I've been drilling these out on the fabbed boards but it would probably be best if I just leave a notch out of each corner. I don't see a mechanical need to secure the PCB in addition to soldering the ESP32 to it.

doudar, 2020-12-17:
3'rd issue is the silkscreen needs to be improved. I don't need all of the pins labeled but it would be nice to better mark the daughter boards orientation as well as polarity on the connectors.

doudar, 2020-12-22:
All issues referenced and 2'nd iteration is in the Hardware library and sent to China for manufacture.

Closed 2020-12-22.

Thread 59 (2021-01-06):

Sorting Out WiFi Distance Issues

doudar, 2021-01-06:
@h2zero,

I know this is one of your guys favorite topics, but....

Any way to get more range out of the ESP32 WiFi these days with both BLE and WiFi running at the same time (without using esp-idf)?

It seems some of this projects users are having issues with WiFi connectivity at reasonable distances from their routers. Phones and computers can stream videos in these areas and have never had an issue.

We're using WiFi on this project for an occasional user interface and OTA updates while continuously using the BLE for connection to 2 servers and one client for fitness data (Needs to be refreshed at about 1hz). BLE scans mostly happen at boot but occasionally the user will manually select them during run.

Thanks for any help - I might have to send you another beer :)

doudar, 2021-01-06:
I changed (increased) my vTaskDelays() in the task that sends BLE notifications from 500ms to 1000ms. Webserver seems a little more responsive. I don't have signal/distance issues with mine, I'm starting to wonder if it has something to do with timing on wireless mesh networks.

h2zero, 2021-01-06:
Well, where do I start... lol. This can be a problematic issue that begins with the single antenna we have to work with. To cut the answer short here are some things to try:

- If scanning, try to keep the window time around 100ms or more greater than the interval time to give WiFi a chance to ping.
- If advertising, same idea, leave some antenna time for WiFi
- as a server try to request connection parameters with min and max intervals greater than 50ms, same trend here :)
- as a client use min and max intervals higher than 50ms and be conservative with the supervision timeout (2 seconds is good)

The RF frequencies of WiFi and BLE are in direct conflict at all times so we need to manage expectations here. Best results come from not mixing the 2 operations, instead opt for a 1 then the other sequence when possible. i.e get all the BLE data operations etc done then deal with WiFi stuff, repeat.

doudar, 2021-01-06:
h2zero - As always, thanks!

I'll give that a try.

h2zero, 2021-01-06:
It can be a lot of trial and error, what I do in my home automation project is scan > connect (if needed) > get data > disconnect > send to MQTT (reconnect WiFi first if needed). This is controlling my furnace etc. so I prioritize the BLE data and controlling things locally over sending the data to a server which loses connection occasionally (so my heat still works if the internet goes down 😄).

It's really stable once you get the settings sorted.

doudar, 2021-01-06:
Well, the good news is that even though all these things are going on (client, server and wifi), none of it is terribly fast. I can get away with 1000ms intervals on the BLE data per device. If I can negotiate it. I honestly think that advertising alone prior to device connection that may have been the source of my issues. I had left the interval at the default. MAX is now 260, min is 160.

h2zero, 2021-01-06:
It depends on the throughput you need vs packet loss expected. If the environment is noisy you'll need more forgiveness (longer timeout). I home that 70ms was a typo, much too small.

doudar, 2021-01-06:
pServer->updateConnParams(desc->conn_handle, 40, 50, 0, 70);

This is my current settings, I just followed some examples and increased them a bit. Any suggestions?

h2zero, 2021-01-06:
Oh, that's 700ms in your settings (*10, BLE spec), that's better then. If you still have issues try setting it to 200.

doudar, 2021-01-06:
Ahhh I see that now....I probably need to get some rest :) The logical part of my brain is getting mushy :)

doudar, 2021-01-06:
And just to clarify, when you say 200 you actually mean 20? Correct? (200ms)

doudar, 2021-01-06:
7

h2zero, 2021-01-06:
Actually I meant 200 as in 2000ms, you'll have a better chance maintaining the connection with lots of stuff going on. Too short and you'll get lots of disconnections.

Closed 2021-01-06.

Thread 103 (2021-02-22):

Power field from FTMS as input?

drz01, 2021-02-22:
Finally resumed testing from the weekend; sorry for the long absence. It appears my bike console has undocumented FTMS implementation! It broadcasts itself as a bidirectional controller (which it definitely is not) and therefore not currently captured in SS2K. Both power and cadence can be isolated in Zwift.

I presume the power is being calculated rather than measured, as a function of cadence and resistance; though it appears to be reasonably accurate! I have even decided against a pedal meter for now. I shall try to look for FTMS documentation of the power field, though all this BLE talk is completely over my head...

Surely this cannot be an isolated case? I perceive widespread use of OEM generic parts...

doudar, 2021-02-22:
Awesome news!

FTMS support is something @kadaan and I are currently working on. Hopefully we have a stable binary ready for an OTA update in the next week.

We're probably also going to be implementing a calibration slider on the web page (where you can multiply the power by a %) because a lot of these bikes are pretty inaccurate without. I've got mixed feelings about the slider though because it makes cheating easy.

kadaan, 2021-02-23:
@drz01 What kind of bike?  Can you share the FTMS packet?

drz01, 2021-02-23:
@kadaan A Lifespan SM-400. Does this count?
[Zwift log BLE snippet.txt](https://github.com/doudar/SmartSpin2k/files/6029050/Zwift.log.BLE.snippet.txt)

kadaan, 2021-02-23:
Unfortunately those logs don’t contain the raw info needed to see if this will work. I thought you were trying with the FTMS branch, but sounds like you are not. When you are able to use that code, we will have a better idea what is going on.

doudar, 2021-02-23:
Once we have the new changes merged into main, I can post a binary here for @drz01 to try and hopefully it will "just work". Either way it should report his FTMS packet back through Telegram

drz01, 2021-02-24:
Flashed the last test build anyway *which didn't just work); but did it send a Telegram?

drz01, 2021-02-24:
[ESP32 log snippet.txt](https://github.com/doudar/SmartSpin2k/files/6033413/ESP32.log.snippet.txt)

Flashed the last FTMS build anyway; not quite there, I'll see if can get Telegram to send...

kadaan, 2021-02-24:
If you have an iPhone can you install nRF Connect and see if you can find your bike. If you locate it, you should be able to connect and see the services on the client and determine what BLE service it is exposing.

drz01, 2021-02-24:
[nRF log.txt](https://github.com/doudar/SmartSpin2k/files/6034236/nRF.log.txt)

kadaan, 2021-02-24:
By change was SmartSpin2k on when you ran this nRF scan?  I just want to be sure that the Fitness Machine Services are not SS2K

drz01, 2021-02-24:
The log was not universal, but specific to each manually/exclusively connected device in-app; the hostname "ZV-E31E6" remains constant in every encountered setting -- as was "ss2k", which I switched off at the wall.

Hmm is Telegram being blocked at a TCP port? Need a log for that too...

doudar, 2021-03-01:
Telegram shouldn't be getting blocked, however if you compiled SS2K from your own repository, it won't have the correct telegram secrets required for communication (unless you provided your own telegram bot info).

drz01, 2021-03-03:
This was from the first FTMS branch build; saw error messages on the console. Not getting my own test builds yet -- still battling through bunch of VSC gremlins!

doudar, 2021-03-19:
With the recent success of Echelon support, I'd really like to get more information .

There have been new methods in NimBLE to request the preferred connection parameters from servers. I wonder if this is a case where that may need to be used as it seems like the connection isn't completing because of a connection parameter (timing) issue.

You could try this binary (use the SS2K flash tool) to test some timings that are newish from the Echelon branch:
[firmware.zip](https://github.com/doudar/SmartSpin2k/files/6168403/firmware.zip)

drz01, 2021-03-19:
Any [closer?](https://pastebin.com/eBX2eWnW)

I think this was up to date, but I also built with the latest merges just to see.

Currently battling my new FAU with no output -- everything is so hard!

doudar, 2021-03-20:
Any chance you can connect to it with the NFR connect phone app and take pictures of all the services it provides? The best is if you can send us a screen shot of what the data string looks like after you subscribe to notifications (triple down arrow icon) of the "indoor bike data" characteristic - 0x1826.

drz01, 2021-03-20:
Was [this](https://github.com/doudar/SmartSpin2k/issues/103#issuecomment-784872801) not it?

doudar, 2021-03-20:
Ah okay - Yes that will work. I was expecting a screen shot. Thx

doudar, 2021-03-20:
The issue is that it isn't hosting one of the services we're looking for. I'll see if we can plot a workaround

Closed 2021-04-24.

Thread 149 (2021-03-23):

[FR] Larger range of values for "Shift Step" setting

bau-sec, 2021-03-23:
**Is your feature request related to a problem? Please describe.**
My bike, the Joroto X2, seems to need more turns than other models to achieve the target change of 50W/shift step. I need 2-3 full turns of the knob to move up 50W (80W to 130W) w/ a cadence of 90. Based on the allowed range, I'm guessing other bikes need less than a full turn for this level of resistance.

**Describe the solution you'd like**
It seems like 1 turn requires a shift step of somewhere around 2250. What's the formula for degrees of ration for shift step? For 2 full turns I'd need a shift step of 4500. So ideally I could set the shift step to this value with the slider. Currently I've been just modifying the slider component w/ my browser to allow setting a higher value (the SS2K doesn't validate this value).

**Describe alternatives you've considered**
The alternative is just pressing the shift button a lot, which isn't a show stopper but it's not ideal.

**Additional context**
Possible suggestion for the setting: change this to setting "shift step" in degrees. Reading through the code I can see this value is microsteps on the stepper motor, but that changes depending on stepper motor settings. Most users won't have any context for what this value means, but would understand 360 degrees = one spin of the knob, 180 = half spin, etc. And if they're like me before having the SS2K they were doing erg mode manually during workouts so they probably have an idea of how many watts a turn corresponds to.

Probably a separate issue, but in general the SS2K ESP32 code should be validating the input it receives from the web forms and that they fall in an acceptible range. "shift step" might be harmless, but "stepper power" could be problematic.

kadaan, 2021-03-24:
Interesting idea.  To calibrate SS2K to a bike, the users would need to be able to figure out how much to turn the knob to get a ~50w increase.  On my spin bike there is no visible power output.  Once could use Kinetic app, or something similar, to figure out how many turns (or fraction of a turn) results in the desired wattage increase.

@doudar I'll defer to you on the TMC2225/stepper/gearing to see if this is something that can work.

@bau-sec Totally right on the data validation.  I created #151

kadaan, 2021-03-24:
@doudar Any reason to increase the slider max value as an immediate for for @bau-sec ?

doudar, 2021-03-24:
There's no downside to increasing the range of the slider other than loss of fine adjustability. This could be offset by implementing + - buttons on either side of the sliders.

The incline multiplier should also be increased as that's essentially how much the computer turns the knob for incline amount. It functions similarly to the "difficulty slider" in Zwift.

The two settings are probably linearly correlated and may also be redundant but I found to error on the side of more adjustability is better atm.

I've thought a bunch about the units and weather to simplify them somewhat but that's when I decided on the slider method vs just an input box. It also enabled a simple means for client side data validation (server validation is needed). With two separate gear ratios in use, I'm not certain degrees of rotation is appropriate but maybe we could add an approximation table in the wiki or something?

doudar, 2021-03-24:
Also, the stepper power is capped on the hardware side by the potentiometer. We can only obtain actual power values less than the hardware set limit.

doudar, 2021-03-24:
As to steps/revolution, it should be motor steps per revolution*microsteps*gear ratio.

For the current setup that's:
200*4* 2.7272 = 2,181.76

bau-sec, 2021-03-24:
> The incline multiplier should also be increased as that's essentially how much the computer turns the knob for incline amount. It functions similarly to the "difficulty slider" in Zwift.

This is something I considered as well. I was thinking of making a separate issue depending on discussion here, but it really is the same core issue: num_turns / watt is different for different bikes. Currently in erg mode I have to "help" by shifting up or down on big watt target changes, otherwise it takes 30-60 seconds to move up on its own.

Maybe the settings stay separate; they stay sliders but with higher max values. I'd think the value on the "shift step" setting should be upped to 5000. Not sure on the equivalent max value for the multiplier. To better communicate to users you could have some javascript generated label/text under the sliders that says something like `Rotate X.X times per shift`. For the multiplier: `Rotate X.X times on big Incline/erg adjustments; Y.Y times for small adjustments` Then users could try to get the shift value to be equivalent to the label for big incline/erg adjustments. Then you have something tying the 2 values together while keeping them independent if users want that.

> I'm not certain degrees of rotation is appropriate but maybe we could add an approximation table in the wiki or something?

Yeah, I'm not sure how meaningful/conventional/appropriate degrees as a unit are either. My only other thought there is that degrees are independent of stepper motor settings. In the future there might be some reason where internally it made sense to use a bigger/smaller step, then your setting either has to be scaled or changed to the new number of microsteps. Same issue if you replaced the stepper motor in a future revision.

kadaan, 2021-03-24:
@bau-sec Do you have to "help" the shifting even if you up the shifter step?

bau-sec, 2021-03-24:
>
>
> @bau-sec Do you have to "help" the shifting even if you up the shifter step?

I have the *multiplier* set to `5` and the *shift step* set to `4500`. The helping is only during erg mode. Looking at the code I think erg would be fixed just injecting a higher *multiplier* from my browser, maybe a value of 10-15 if it scales the same as the shift step? I'd have to experiment.

doudar, 2021-03-24:
`injecting a higher multiplier from my browser`

Someone's discovered one of my secret testing methods :)

doudar, 2021-03-24:
> > @bau-sec Do you have to "help" the shifting even if you up the shifter step?
>
> I have the _multiplier_ set to `5` and the _shift step_ set to `4500`. The helping is only during erg mode. Looking at the code I >think erg would be fixed just injecting a higher _multiplier_ from my browser, maybe a value of 10-15 if it scales the same as >the shift step? I'd have to experiment.

The incline multiplier will help. Ultimately what needs to be done is to make the multiple inside the ERG code user definable. The .5, 1 and 3 in the code below:

`void computeERG(int currentWatts, int setPoint)
{
  //cooldownTimer--;

  float incline = userConfig.getIncline();
  int cad = userConfig.getSimulatedCad();
  int newIncline = incline;
  int amountToChangeIncline = 0;

  if (cad > 20)
  {
    if (abs(currentWatts - setPoint) < 50)
    {
      amountToChangeIncline = (currentWatts - setPoint) * .5;
    }
    if (abs(currentWatts - setPoint) > 50)
    {
      amountToChangeIncline = amountToChangeIncline + ((currentWatts - setPoint)) * 1;
    }
    amountToChangeIncline = amountToChangeIncline / ((currentWatts / 100) + 1);
  }

  if (abs(amountToChangeIncline) > userConfig.getShiftStep() * 3)
  {
    if (amountToChangeIncline > 0)
    {
      amountToChangeIncline = userConfig.getShiftStep() * 3;
    }
    if (amountToChangeIncline < 0)
    {
      amountToChangeIncline = -(userConfig.getShiftStep() * 3);
    }
  }

  newIncline = incline - amountToChangeIncline; //  }
  userConfig.setIncline(newIncline);
}`

 The first block is a 50w "deadband". It could probably be smaller. The second block is a more aggressive band for when the power is outside the deadband. This should/could probably scale somewhat linearly with an absolute cap (as power spikes and power drops do happen).

kadaan, 2021-03-24:
Basically you are trying to have it scale down/up faster if the requested change is greater, right?

doudar, 2021-03-24:
> Basically you are trying to have it scale down/up faster if the requested change is greater, right?

Yes. And the deadband keeps it from oscillation at the set point - one of the things I hate about erg mode on my elite direto trainer.

Closed 2021-05-18.

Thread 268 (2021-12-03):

[FR] ERG Mode needs TLC (and math....lots of math...)

doudar, 2021-12-03:
**Is your feature request related to a problem? Please describe.**

A great ERG mode has been fighting me for a long time due to the variability (and sometimes completely nowhere near linear resistance) of spin bikes. Because of this, I've only managed meh ERG mode.

**Describe the solution you'd like**

I think it may need some type of learning algorithm where it builds a small lookup table that says "I'm at 90 rpm at X power and need to get to Y setpoint - last time that took z steps, so I'll move z steps." The issues are the previously mentioned non-linear response, variable pedaling cadence and total system delay from when a set point is received to when the new power is read from the power meter.

**Describe alternatives you've considered**

It's possible a proper tuned PID loop may work but the last time I tried PID here I failed miserably.

**Additional context**

ERG code starts around line 210 in BLE_Server.cpp if anyone wants to try to tackle it. It's a fun and complex problem to try to solve.

MarkusSchneider, 2021-12-03:
I also failed ;) tried it last winter.
The main problem is that we need the power measurement more frequent.

A cycle time of 1 sec is to slow.
I think the current algorithm is not so bad. A spinning bike has an nonlinear curve when cadence changes.
With higher cadence the wheel is spinning faster, produce more friction and a change of incline has a bigger impact.

My recommendation is to decouple the ERG calculation cycle from the notification cycle from Zwift and increase the cycle time of power measurement.
1) Create a new vTask with a 100 ms cycle Time. Calculate incline with current algorithm.
2) Take cadence in account. We can do this by dividing a constant e.g 70 by cadence. With cadence 100 we get then a factor of 0.7 and we can use this factor [her](https://github.com/doudar/SmartSpin2k/blob/develop/src/BLE_Server.cpp#L244), likely we use the ERG Sensitivity.
3) We must read out Power Meter or Heart Rate more frequent by increasing the BLE_CLIENT_DELAY, I guess

The reaction time of the whole loop could be a problem. But this time depends on the setup of the bike, stepper, power meter.
But if we read power more frequent and compare them with the Setpoint we can correct them quick.
We should than introduce a hysteresis, a band around the Setpoint where no Incline change is made.

doudar, 2021-12-03:
If you wanted to add another task, try moving everything out of the loop() in main.cpp except add vTaskDelete(NULL);. That way we should be able to free up some resources that aren't really being used for anything much. I'm guessing the default loop task allocates a pretty big stack as well so it's been on my list of things to ditch and this would be a perfect opportunity.

The only things in loop() right now are; checking to see if a shift happened and logging it (Has to happen outside the interrupt because it takes too long). And loop counter/timer that checks driver temperature and if the shifters have been held down for 4 consecutive loops (seconds). There's no reason that either couldn't be moved to any other loop and just check millis(). Every time the CheckDriverTemperature() is run it will log a message if the driver is too hot so we definitely don't want that getting called too often.    \

Then you can spawn your new task from setup() and run it as fast as you'd like. I'm sure there's probably already plenty of power left to add a new task without removing loop() but I'd like to try to keep things as balanced as possible moving forward because we're asking quite a lot out of this microprocessor (and were nowhere near running out of ideas yet.)

I'm on vacation starting tomorrow, so hopefully you don't hear much out of me this upcoming week.

MarkusSchneider, 2021-12-05:
Hi, I did some research to find out how my spinning bike behaves.

The relation between cadence and power is almost linear:
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

Between the series I changed the resistance manually. Higher series No -> higher resistance.

Relation between Incline (Shifter Step) and Power is exponential when cadence stays same:
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

Maybe someone can do the same research on his bike, then we can compare the curves.
For ERG computation we must use an exponential function to guess the next incline and it would be good to use cadence change as an additional factor.

To calculate the next incline we need a triple of Stepper Position, Cadence, Power. Ideally all at the same time.
Cadance and Power should be created at the same time but this depends on the power meter. To get the Position of the stepper the [getCurrentPosition](https://github.com/gin66/FastAccelStepper/blob/master/src/FastAccelStepper.h#L142) can be used.

It could be a problem when power measurement takes long, the stepper reached the final position and the final position is not producing the requested power.
The whole system gets then unstable. We get than is curve with inclines with huge under and overflows.
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

If we can compute incline frequently, a correction of the first computation can be made before the stepper reaches the final position and with every cycle we getting closer the the target.

doudar, 2021-12-06:
Great information! I’ll read it over a few times and think it over this week.

MarkusSchneider, 2021-12-07:
Hi,
I tried to speed up the BLE notification cycle of my Power-Meter Pedals with no luck.
Assioma sends every ~1 Second one Cadence and Power value via Notification.
I've opened a support request to assioma to clarify if it is possible to get the values more frequent.
But I believe this would not be possible.

If we can not get power values more frequent the only way to make ERG faster is to compute target incline better.
Then we need viewer cycles to adjust the correct value and hopefully will not get oscillations.

As you can see in my upper comment we need ideally the target-cadence and the target-power.
The target-power value we get from Zwift.  As far as I know do we not get the target-cadence from zwift.
So we missing one (linear) factor for exact computation.

With power value we can use an exponential function to get the target-incline.
The parameters of this function may depend on the bike configuration, we have to verify this.
First approach is to implement fix parameters and make a test ride.

I'll keep you up to date :)

MarkusSchneider, 2021-12-07:
Tried it with no effect. Seems that this Setting (60, 200, ...) only impacts the connection interval and notifications is only sent when value changes, new value is collected. I guess that the power meter collects only one value per seconds (more than enough for power measurement but not sufficient for controlling :))

doudar, 2021-12-07:
Oh, I gotcha. You’re able to receive at intervals less than one second but the pedals only recalculate the value every second.

Does the value update faster if your cadence is higher? Maybe it takes one or two full crank revolutions for the pedals to calculate power?

MarkusSchneider, 2021-12-07:
mmh... getting power measurement faster than one revolution will not make sense.
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
doudar, 2021-12-22:
@MarkusSchneider . I was able to get a few minutes to test your changes. You fixed the erroneous table input and the table input seems to be working very well!!!

This is going to be great - Overall it's working very nice but maybe it isn't picking up the correct pairs of results? The output jumped nicely on ERG target changes. From high target watts to low target watts it was pretty much spot on. From low target watts to high target watts, the table result seemed a little too low. Still not bad, just a touch too low. And this is on a *very* difficult to control felt resistance bike.

Very impressive so far!

Tons of data in the log for you vv
https://pastebin.com/VwLmWreD

doudar, 2021-12-22:
Thinking about this a bit, I’m guessing the cadence correction is probably a bit too much for my bike. @MarkusSchneider , should we decrease it or do you think there’s a way to generate it dynamically via the powertable data. Maybe look for similar inputs in the pre-buffer and check their watt/cadence/target relationship?

doudar, 2021-12-23:
I changed my mind. After doing another test ride, the power table lookup function seems to be spot on with the numbers it’s producing. Need more testing though

MarkusSchneider, 2021-12-23:
I think we must understand the spinning bikes better. I like to create a function to collection bike characteristics. To create a chart like:
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

For the first version I have a simple logging in mind [see](https://github.com/MarkusSchneider/SmartSpin2k/blob/develop/src/ERG_Mode.cpp#L85) enabled by an option in the Bluetooth Simulator page.
You can then create different statistics e.g.
- Keep Stepper steps constant, change cadence -> We get the CAD/POW factor
- Increase Stepper steps, keep cadence constant -> We can check if higher friction behaves linear or not

doudar, 2021-12-23:
After putting the SS2K on my magnetic resistance bike, I figured out where the issue is with not setting the correct resistance after powertable::lookup.

If lookup commanded a move that took longer than erg_task delay, the regular erg task overrode the lookup move partway through it.

To solve this, I added a while(rtConfig.getTargetIncline!=rtConfig.getCurrentIncline){vTaskDelay(100/portTICK_PERIOD_MS);}

The output was spot on and it’s starting to look pretty good!!!! The response was absolutely as good as my wheel off bike trainer.

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

MarkusSchneider, 2021-12-23:
Awesome, good work Anthony 👍
I also think that we need calibration and it should not be a problem.
Let's try the new erg mode and wait for feedback. If you like, we can create an option to switch between old an new ERG-Mode.

In future we can create an automatism to determine erg-sensitivity but for now I'm absolutely happy with our result 😊

doudar, 2021-12-23:
> Awesome, good work Anthony 👍 I also think that we need calibration and it should not be a problem. Let's try the new erg mode and wait for feedback. If you like, we can create an option to switch between old an new ERG-Mode.
>
> In future we can create an automatism to determine erg-sensitivity but for now I'm absolutely happy with our result 😊

@MarkusSchneider, One more bug needs to be fixed on it before merging. If I pause a workout in Zwift, 50% of the time I’m getting “ERG Request received but no PM connected”. I don’t have it in a log currently for you, I’ll see if I can catch it in a log later.

MarkusSchneider, 2021-12-24:
Ok, I'll debug it. Looks like erg_mode is disabled if you pause the workout an not enabled after resuming.

doudar, 2021-12-24:
When you press pause, I think it just switches to Sim mode, then back to ERG mode when unpause/resume.

MarkusSchneider, 2021-12-24:
It's maybe only an erroneous log because when you pause, erg_mode is disabled but targetWatts not reset to 0.
Can you try to set targetWatts to 0 if ErgMode is disable:
https://github.com/MarkusSchneider/SmartSpin2k/blob/develop/include/SmartSpin_parameters.h#L80
void setERGMode(bool erg) { ERGMode = erg;  if(!erg) {targetWatts = 0;}}

After resuming all should start again with the first sending of targetWatts by zwift.
I'll try it tomorrow.

I also like to do same smaller changes:
- Only run ERG if powerValue > 0 or >10 like you do in PowerTable.
- Update PowerEntry only if a new Measurement is present by comparing the timestamp of last and current powerValue

Happy Christmas
Markus

doudar, 2021-12-24:
Merry Christmas to you too Markus!

I found the issue and corrected it on my end. If ERG mode was turned off and rtConfig.getTargetWatts>0 , it would send that message. I just added (line 73) to setTargetWatts(0); if that is the case.

doudar, 2021-12-27:
Very happy to close this one. Fixed with #282

Closed 2021-12-27.

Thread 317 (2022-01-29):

Strange behavior (debug messages "no data in powertable" and "temperature now under control")

holger8080, 2022-01-29:
Hi all,

I switched back to Zwift and used my indoor bike more often again recently.
While last fall Zwift and the smartspin with the old firmware worked flawlessly, I'm now having a lot of problems.
I have a Schwinn IC4, Assioma Unos, and updated the smartspin2k to the latest firmware "1.12.30-develop".

Problems include:

- if I use smartspin without Zwift or any connection to any app or device and I just want to use the up or down buttons, there will be "random" behavior after a while. I don't press any button, yet the resistance is going up or down. There is no ERG connected, so why is the resistance changing?
- There are lots of debug messages saying that "no data found in powertable" and "temperature is now under control". Looking at the main.cpp code (but not understanding it fully ;-)  ), that debug message should only appear in pairs with a previous "overtemp" debug message, shouldn't it? But they don't.
- listening to the noise the stepper motor makes, it seems to hit a torque limit sometimes. I never had these problems with the v1.16 firmware (and downgraded to confirm it's no HW issue) with the same "stepper motor power" settings. Changing them didn't have much of an effect with the 1.12.30 firmware. Could there be a link to the "overtemp" reset?

Debug log excerpt when pressing up/down buttons:
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

When I downgraded to the old v1.16 firmware, all these problems were gone (so it doesn't seem to be a faulty HW), but of course Zwift doesn't work anymore.

Could there be a memory leak or sth like that? How else could the debug message "Temperature is now under control. Driver current reset." appear without ever showing "Overtemp! Driver is throttleing down!" ?

Is there any short-term workaround (downgrade etc) I can do to get Zwift to work but don't run into these problems?

Would appreciate some help.
And: thanks for the project, using smartspin2k on my Schwinn with Zwift really helps me clear my mind, so your work is highly appreciated. :-)

MarkusSchneider, 2022-01-29:
Hi Holger,
- random resistance changes: I looked over the code but could not find the problem. I'll do a test today to see if I can reproduce it. If you are not connected to zwift, resistance is controlled by shifters and there are two way to set shifter
   1) via shifter butten,
   2) via html shifter settings page.
- Log-Message:
  - "Overtemp!" is written with log level warning
(https://github.com/doudar/SmartSpin2k/blob/a6220ed6808148208abfc6ff671c702c26b77718/src/Main.cpp#L372)
my be the reason why it is not present in log output.
  - ERG_Mode: "No data found in powertable.". You can ignore this message. If you are interested in details [see](https://github.com/doudar/SmartSpin2k/issues/268#issuecomment-999652893)
- stepper noise: Have you tried to increase / decrease stepper current, enabled/disabled stealthchop? I don't have any noise from stepper with the defaults.
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

you can merge: https://github.com/doudar/SmartSpin2k/blob/a6220ed6808148208abfc6ff671c702c26b77718/src/BLE_Server.cpp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
down to the latest version that worked for you. Zwift should then work again.

doudar, 2022-01-29:
It’s interesting that you don’t have the driver temp messages with the older firmware. They’re typically displayed when a motor driver with no/bad/incompatible uart interface is used. @eMadman discovered fystec had batch of 2208’s where the uart doesn’t work. Symptoms are the driver temp warning and not being able to set the driver current.

I’ll check and see what differences there are between 1.16 and the current version with regard to driver code and shifter denounce and get back to you later today.

Thanks for the report!

MarkusSchneider, 2022-01-29:
Did a quick test with a duration ~10 Min. I don't have any problems with resistance changing. @holger8080 can you check your logs if you have "shifter message" in the log when you have this problem (Shift DOWN or Shift UP).
Just to verify that it is not a problem with the micro switches or wires.

@doudar I'm seeing  the "Temperature is now under control. Driver current reset." log message too.
Were cycling for ~ 1h and had this message. "Overtemp" message was not logged.

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

doudar, 2022-01-29:
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

I guess we should change that LOGW to a regular LOG so that we can get more information (The actual reported driver temperature is logged there). Do you think there's a chance that your driver maybe did get hot since you've not seen this message before?

MarkusSchneider, 2022-01-29:
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

Maybe. Did a workout with ERG for around 1h.

holger8080, 2022-01-29:
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

Thanks so much for your fast response!
A few more details:
- I got the overheat message a few seconds after I switched the smartspin2k on. Consistently, when I press Shift up or down, the knob makes some small move and the "temperature now under control" message appears.
- I also had problems 30 mins in
- the torque is so low (at any(!) setting of stepper motor power) that I can easily stop the knob with one single finger; with the old firmware there was plenty of power even at tow torque settings

@MarkusSchneider: Shifter messages do appear:
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

I did try to merge the "case FitnessMachineControlPointProcedure::Reset:" case to the old firmware, but I keep getting some error messages while building (some platformio build issues) and didn't have the time to get it fixed.

MarkusSchneider, 2022-01-29:
@holger8080 I can try to compile for you what version is the one that worked for you? I can not find a version 1.16.
Please see here: https://github.com/doudar/SmartSpin2k/tags for a list of release versions.

holger8080, 2022-01-29:
>

I

> @holger8080 I can try to compile for you a new binary. What version is the one that worked for you? I can not find a version 1.16. Please see here: https://github.com/doudar/SmartSpin2k/tags for a list of release versions.

I meant this one here:
https://github.com/doudar/SmartSpin2k/releases/tag/1.6.19

😬 almost "1.16" 😅, sorry for that. And I'd really appreciate your help! :-)

MarkusSchneider, 2022-01-30:
@holger8080 Merged Reset Command into BLE Server and created a new Binary. I've removed automatic firmware update to avoid update with new version. You have to do this manually.

To update go to http://smartspin2k.local/ -> Update Firmware upload firmware.bin
I've tested connection with Zwift with erg and it was working.

[firmware.zip](https://github.com/doudar/SmartSpin2k/files/7965747/firmware.zip)
[spiffs.zip](https://github.com/doudar/SmartSpin2k/files/7965748/spiffs.zip)

bdattilo, 2022-01-31:
@MarkusSchneider I have this same issue - what is the username and password on the ESP32 login page?

Also - have the same issue as this when flashing via the SmartSpin2kFlasher: https://github.com/doudar/SmartSpin2k/discussions/306

doudar, 2022-01-31:
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

admin/admin .

Not saving is most likely due to a full spiffs partition. Try a reset. You'll also have to manually upload all of the files  one at a time from your versions /data folder. You cannot upload spiffs.bin yet.

Closed 2022-09-06.

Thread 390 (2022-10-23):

Shifters in Stand-alone ERG mode

Flo100, 2022-10-23:
I just found your SmartSpin2k project, build it, adapted it to my already made (and older) hardware setup and I really like it. :)

**Is your feature request related to a problem? Please describe.**
There's not really a problem, it;'s more inconvenience.
Sometimes I use my spinning bike stand-alone and choose the ERG mode from the webserver and set ERG target Watts. But during my excercise I would like to change this target using the shifters, because using the webinterface is annoying during a workout.

**Describe the solution you'd like**
Let the shifters increase and decrease the ERG target Watts in ERG mode. For example in 10Watt steps or so.
Also it would be great that the Watts go to minimum Watts when the shift down button is held for 1,5s. That way you don't have to push the button that many times to release the resistance. (Could also work for gears in SIM mode to switch back faster).

**Describe alternatives you've considered**
Using my phone on the handlebar to change the slider in de webinterface.

I noticed that I can't switch on ERG mode when connected to RGT or Zwift. Would it be possible that the webinterface ERG setting overrides the incline data from RGT so I can ride any event on targeted Watts instead of incline (but still sending all cadence, hr and powerdata to RGT)?

doudar, 2022-10-24:
> I just found your SmartSpin2k project, build it, adapted it to my already made (and older) hardware setup and I really like it. :)
>
**Awesome! Glad to have you here!!!**

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

**Holding down the shifters - I like it! That's a pretty cool idea. I'll definitely put it on my todo list. Changing target watts in ERG mode is interesting as well. I think it's something that could be done.**

> **Describe alternatives you've considered** Using my phone on the handlebar to change the slider in de webinterface.
>
> I noticed that I can't switch on ERG mode when connected to RGT or Zwift. Would it be possible that the webinterface ERG setting overrides the incline data from RGT so I can ride any event on targeted Watts instead of incline (but still sending all cadence, hr and powerdata to RGT)?
**This one might be a little bit harder to implement correctly, but I'll think about it and look into it. In the meantime with Zwift, you could work around this by only connecting SS2k as a power meter and not a controllable trainer. **

Flo100, 2022-10-24:
I made a simple version a few years ago with a stepper motor and an A4988 and it works like Smartspin2k when not connected to Zwift, so only changing the resistance by pressing the shifters. I quickly got tired of pushing multiple times to get a large increase or decrease and so I implemented big steps when holding down the button for 1,5s.

It also has a hardware switch and let the stepper "zero" itself when powering on.
I noticed with SmartSpin2k that when I start on a hill the motor keeps spinning backwards until it is mechanical limited and crashes. (Unless I switch up at the same time offcourse)
How do I tell SmartSpin2k that the stepper is already at minimum steps when I power up? Or do I always have to start with the stepper like halfway my resistance?
Perhaps it should only decrease in SIM mode if the measured power > min_watts? Or does that break something else / do I do something wrong here?

> This one might be a little bit harder to implement correctly, but I'll think about it and look into it. In the meantime with Zwift, you could work around this by only connecting SS2k as a power meter and not a controllable trainer.

That is a possibility offcourse. I mostly start a course in sim mode and when I'm done I tend to keep riding on the same course to do my cooling down. During the cooldown I don't like the automatic resistance change and would rather stay at a (manually) set power level.

doudar, 2022-10-26:
If you’re using a new version of SS2K and have some type of power meter attached, it will generate travel limits as you’re pedaling. These are base off min brake watts and max brake watts and SS2K won’t let you go above or below those respectively.

Flo100, 2022-12-25:
It does that only in ERG mode right? Not in simulation mode?
When I start on top of a hill in simulation mode, my stepper rotates back beyond it's mechanical limit.

doudar, 2022-12-25:
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

Good catch! Yes, it should be.

Right now, the power table isn't persistent so it takes a few minutes of pedaling at various watt levels before the min and max positions are calculated. Prior to that, the limits are very large and the knob could crash.

What I'd like to do is have the offsets for the table saved and then the table regenerated once a known position is found. That should give you protection after just a few seconds of pedaling.

doudar, 2022-12-25:
> It does that only in ERG mode right? Not in simulation mode? When I start on top of a hill in simulation mode, my stepper rotates back beyond it's mechanical limit.
>
> Also I think that MIN_WATTS needs to be replaced by userConfig.getMinwatts() in ERG_Mode.cpp? ` // set minimum SetPoint to MIN_WATTS if app sends setpoints lower than MIN_WATTS. if (newSetPoint < userConfig.getMinWatts()) { SS2K_LOG(ERG_MODE_LOG_TAG, "ERG Target Below Minumum Value."); newSetPoint = userConfig.getMinWatts(); }`

Current changes (you suggested) are going into the FTMS_Resistance branch, as that is currently undergoing testing for merging into develop. If you're interested in working on a persistent power table, I'd absolutely love the help. No pressure of course.

Flo100, 2022-12-27:
> This one might be a little bit harder to implement correctly, but I'll think about it and look into it. In the meantime with Zwift, you could work around this by only connecting SS2k as a power meter and not a controllable trainer.

I implemented a simple 'solution' to this one.
In SmartSpin_parameters.h change _getERGMode()_ to:
`bool getERGMode() { return ERGMode || simulateTargetWatts; }`
And in BLE_Server.cpp change _case FitnessMachineControlPointProcedure::SetIndoorBikeSimulationParameters: {_  to:
`...`
`port = bytes_to_u16(buf[1], buf[0]);`
`rtConfig.setERGMode(false);`
 `if(!rtConfig.getERGMode()){`
 `  rtConfig.setTargetIncline(port);`
`   logBufLength += snprintf(logBuf + logBufLength, kLogBufCapacity - logBufLength, "-> Sim Mode Incline %2f", rtConfig.getTargetIncline() / 100);`
`}`
 `ftmsStatus = ....`

This way you can "Override" the simulation mode using the webinterface and ride with a fixed Powersetting. I use this when cooling down, because then I don't like the shifting up and down anymore.
Also when RGT (or Zwift) is set to ERG mode RGT is still leading and the Set Power can't be altered during the workout using SmartSpin2k.

> Holding down the shifters - I like it! That's a pretty cool idea. I'll definitely put it on my todo list. Changing target watts in ERG mode is interesting as well. I think it's something that could be done.
I also made changes to the Interrupt Functions of Main.cpp to get this working.
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
Flo100, 2023-01-10:
On the other hand maybe we can't close it yet.
I discovered that I can switch 1 step back when I'm already at minResistance and one step up when already at maxResistance.
And then the stepper slowly steps back to the correct target and keeps repeating over and over because the shifterposition is still to low or to high.
I changed < and > to <= and >= in line 273 and 274 below so it doesn't switch when it is already on min or max resistance.
`if ((ss2k.targetPosition > rtConfig.getMaxStep()) || (rtConfig.resistance.getValue() >= rtConfig.getMaxResistance()) || (ss2k.targetPosition < rtConfig.getMinStep()) ||
            (rtConfig.resistance.getValue() <= rtConfig.getMinResistance())) {`
https://github.com/doudar/SmartSpin2k/blob/eaa165a81525f1a3f110c330d2e3754652e3e22d/src/Main.cpp#L273-L279

doudar, 2023-01-10:
Whoa! Resistance numbers? That's experimental in this branch - what bike are you using that you're getting resistance feedback? I could really use another tester if you have a bike with resistance! (Especially an Echelon)

Flo100, 2023-01-11:
No sorry, I don't have an Echelon bike.
I made my own setup a few years ago with a simple spinningbike, stepper and nextion display. I mounted a FSR under the felt pad to measure the resistance. I mainly use this when zeroing the stepper at startup and from that point it was just a matter of counting steps and stop at max resistance. I only had the incline from RGT and Zwift working in simulation mode.

I like the ERG mode you implemented, that's why I ported your software to my setup and since it now has resistance too, I thought I'll give it a go.
If I switch fast enough (and keep the stepper spinning) I can still switch beyond the limits because the resistance hasn't changed enough yet for the shifts to be blocked. It obviously did not reach its destination yet (That's why the stepper is still spinning offcourse).
But I don't know if that's normal behaviour for a resistance bike or that it's just my setup.
I use the nextion for displaying the parameters like power, heartrate and cadence and to switch some settings like ERG mode or turn the fan on or off. And offcourse this way I get all the parameters directly on my bike too in stand-alone mode.

doudar, 2023-01-11:
Awesome! That sounds pretty cool!
Your setup is spot on - that's an exact duplicate of the last remaining bug (so far) that we've found in testing with the Peloton.

doudar, 2023-01-11:
Here's a new binary (with @Flo100 's oscillation fix) for anyone else that might be watching this thread. Unzip and make sure it's named exactly firmware.bin then use the web interface admin/admin.

Also, as a reminder, some of the HTML files have also
[firmware.zip](https://github.com/doudar/SmartSpin2k/files/10395951/firmware.zip)
changed in this release so if you manually update, you will have to update those from the FTMS_resistance branch individually as well. You'll find them in the data folder. https://github.com/doudar/SmartSpin2k/tree/FTMS_Resistance/data

Flo100, 2023-01-12:
> Awesome! That sounds pretty cool! Your setup is spot on - that's an exact duplicate of the last remaining bug (so far) that we've found in testing with the Peloton.
>
> The delay is why we have the Peloton resistance limits at 5&98. The actual bike is 0 and 100 but there needs to be a buffer for overshoot.

Before I had BLE working I wanted some sort of reproducable resistance level with each workout and that's why I mounted the FSR. After that used to I find the zero point at startup, reset the stepper to zero and use this as stepper minimum. My FSR gets saturated over time because there is more force on the felt pad than expected and I actually need another type. But I counted the steps to maxResistance once and used that as upper limit.

You could probably do something like that too. Find the zero point at startup and after that use minStep() as boundary.
You can also find the maxStep this way, only it takes some time, so perhaps implement a calibration setting in config which stores maxStep?
If you reset the stepper (stepper->clearPulseCounter()) at the found zero point minStep will be 0 and you only have to store the number of steps until maxResistance (maxStep).
Offcourse this interferes with ERG mode... so minStep and maxStep needs to be initialized after switching modes or perhaps add minResistanceStep and maxResistanceStep?

doudar, 2023-03-08:
Merged into develop for testing.

doudar, 2023-12-18:
Fixed

Closed 2023-12-18.

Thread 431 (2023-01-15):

[BUG] shifter increasing indefinitely (HRM->watts)

ikishk, 2023-01-15:
### Description

HRM->Watts enabled seems to be causing shifter to increase indefinitely, ignoring max watts.  Inclines/shifting does not increase in Zwift, randomly decreases only.

### Steps to reproduce

Load version 22.11.x/22.12.x
reboot a couple times and wait 5-10mins
unit will start increasing resistance by itself... with no paired sensors.

---or---

reboot a couple times until it stops acting weird
pair sensors
start zwift
spin... notice the shifter doesnt increase resistance, only decreases sometimes.

### workaround
disable auto-update
load 22.10.x

### **feature req**
manual "web shifter" limit settings.  While this was happening, the web shifter variable kept increasing.   Having a manual range may help with this, as well as easier to tune limits.  (ie. -5 to 20)

ikishk, 2023-01-23:
Been able to narrow this down to a bug introduced in 22.10.7: "Simplified CAD compensation in Powertable by @doudar in #380"  build from 10/6 has been stable so far

doudar, 2023-01-23:
Awesome - Thanks, that will help to track this down.

ikishk, 2023-01-23:
nope, was able to accidently replicate in 10/6.  was connected to zwift, hit manual shifter... then it kept going.

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

ikishk, 2023-01-23:
went down to 9/5, rebooted, was still shifting up.  power cycled, still shifting up.   loaded 8/18 (release before the previous power merge) and it stopped.  however the footer still shows 9.5.   is it possible the power table and/or assoc files/cache are not clearing out and surviving between firmware revisions?  off to try and ride again!

doudar, 2023-01-23:
That is a bazar bug. Hopefully I can get some time to replicate it on my end soon.

ikishk, 2023-01-23:
gets weirder.. reflashed 8/18, footer updated.  as soon as i connect zwift... it started up again.  disabled HR->pwr, power cycled. connected to zwift, was fine for 10 mins, then it started again.

eMadman, 2023-01-23:
The frequency of these shifts smells like a possible hardware issue?  Can you try unplugging the shifter - do you still have the frequent shift ups?

ikishk, 2023-01-23:
shifter unplugged half the time, debated that.  doesnt seem to make a diff.

is there a way/build/utility to clear out anything thats possibly cached but not lose basic settings?  seems odd this is happening in 8/18?

eMadman, 2023-01-23:
Could you open up the case and disconnect the shifter from the PCB as well?  It's using a JST connector so it should pop right off - just be sure to pull from the plastic housing and not tug on the wires since the crimps may pull out.  Shouldn't happen but it happens sometimes.

doudar, 2023-01-23:
I just did a quick test with hr->pwr and I couldn't duplicate it. I'll try to do a better/longer test tomorrow.

ikishk, 2023-01-24:
8/18 seemed fine w/ shifter jst disconnected for 15mins in zwift.  power cycled a couple times, used webshifter mid zwift (didnt move as expected).   couldnt reproduce as before.  will load up 10/6 tonight and see how that goes tomorrow. (i like hopping over relevant builds, gives ya a fallback if it doesnt work to test the fallback too)

ikishk, 2023-01-24:
full ride on 10/6, no crazy-upshift issue (jst still disconnected)... no shifting at all (auto or webshifter).  gonna go up to 10/8 and test if that #380 made a diff or not

ikishk, 2023-01-25:
10/8 was stable.  random sim shifting maybe 5 times in an hour, webshifter worked 1/3 the time.  going back up to 10/25.  seems this was a defective 3.5mm plug.  feature req w/ hard webshifter limits might have been a good stopgap if this happens to someone else in the future

ikishk, 2023-01-27:
10/25 definitely works as before (with its little annoyances in mind).  had to be a defective 3.5mm.

ikishk, 2023-02-10:
replaced board.  tried all "major" revisions from 22/9/5 to 23/1/24 and could not replicate.  seems to have been bad board.

feedthejim, 2023-04-12:
I'm having the same exact issue @ikishk. Did you have to replace the board or just the 3.5mm plug in the end?

eMadman, 2023-04-12:
> I'm having the same exact issue @ikishk. Did you have to replace the board or just the 3.5mm plug in the end?

In @ikishk's case, it was very likely a bridged solder pad for the shifters.  That's the hardest one to diagnose on the V2 but you might have some luck with by using a multimeter for continuity testing.

It can also be the wiring from the 3.5mm plug to the PCB, the shifter cable, or a short in the shifter housing.

In the case of cable / shifter housing issues, I found I could reproduce it by bending the cable near the housing.  Again, a multimeter may help

I've never actually found a bad 3.5mm plug behaving this way - i've had some faulty ones in terms of tolerances, but never randomly shorting/bridging.

ikishk, 2023-04-12:
old shifters work on the new board tho :) i never reverted to old 3.5mm plug since i already soldered the new one up.  i think it was the board, haven't been able to reproduce since.  many miles put on it thankfully.

Closed 2023-02-10.

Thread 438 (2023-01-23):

[BUG] HW broken? Over temp error and lost bluetooth

xpectnil, 2023-01-23:
First of all and most importantly: thanks to all the people who initiated and contribute to this project.
I've been a silent reader in the past but the smart spin helped me a lot staying sane and fit during the Covid lockdowns.
You work is highly appreciated.

### Description

I have a V1 HW version with an Assioma Uno and a Schwinn IC4 and Trainer Day (same behavior on Zwift) on an iPhone 12 Pro and iPad. I built the HW quite some time ago where it seemed to work well.
The other day, I wanted to use the Smartspin again (my FTP is really down...). I gave the smartspin a reset and updated via USB to the newest Firmware 23.1.22-develop.

I use the suggested settings from the Wiki for the Schwinn IC4.

But I'm getting strange behavior (which may have been the case already before the Firmware update).
Right out of the box, i.e. seconds after booting (and without the motor ever moving) I get an over temp warning.
`[E] (Main): Over temp! Driver is throttling down! ESP32 @ 97.222221 C`

Every component on the PCB has room temperature, I checked. Those warnings pop up every few seconds in the log.
Sometimes, the ERG control loop seems to work; then other times, it doesn't at all.
Bluetooth is connected, the correct power and RPM is shown in the App, but the smartspin debug screen shows Target Power as 0 while it should be 100.

There seems to be a driver reset and bluetooth is (partially?) lost (it's 20 minutes into a ride):

> [192100][E] (Main): Temperature is now under control. Driver current reset

> [1921031(E1 (Main): Scanning from Check BLE Reconnect 0
> [192103][E] (BLE Client): Scanning for BLE servers and putting them into a list

I have Current Watts: 118, Target Watts: 50 in ERG mode - and nothing is happening at all. That's the log of the seconds before.
I don't quite get it. If the bluetooth connection is lost - how can the power still be displayed in my app and seem correct?

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

I'd like to be more helpful in re-creating the bug. I've programmed quite a bit myself before, so I looked into the code, but it's really not obvious to me what is happening here and why.

Could the hardware / ESP32 / stepper motor drivers be broken?
Any way how I could test this easily? Then I'd just go ahead and buy new hardware.

### Steps to reproduce

Turn on device, over temp is shown after a second.

That's the log I get seconds after booting:

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

doudar, 2023-01-23:
Chances are that you have a faulty temp sensor in your esp32 dev kit. I've seen a lot of false indications and never a real one yet. But since this isn't an issue with a good working ESP32, I'm hesitant to disable the temperature check for everyone in case it helps somewhere with an actual overheating situation.

For your own purposes, you could comment out the SS2K temperature check in main at:
https://github.com/doudar/SmartSpin2k/blob/6d38d0fe76222908d80350ce1f96abf6a856a55b/src/Main.cpp#L213
or try increasing the THROTTLE_TEMP in settings.h:
https://github.com/doudar/SmartSpin2k/blob/6d38d0fe76222908d80350ce1f96abf6a856a55b/include/settings.h#L262

I'll do more research and see if this is something we can safely get rid of.

doudar, 2023-01-23:
It shouldn't be causing any problems, but if you aren't using a HR strap, select "none" for your HR device and save. Then SS2K won't periodically scan for a new device as long as your pedals are connected.

xpectnil, 2023-01-23:
Thanks!

I had HR device set to "none" already. The shifters are set up correctly, I just once more checked with the hint you gave - the debug output and motor direction are correct.

I set power meter to "none" and selected my Assioma Uno once again. The Assioma is fully charged and three feet from the SS2k.

Still - all the time I do get a "Scanning from Check BLE Reconnect 0".

I don't really know the code... but: isn't there a bug here in the second if?

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

```
[ 90434][E](Main): Shift -1 pos 0 tgt 0 min -200000000 max 200000000 r_min -2000 r_max 2000
[ 90514][E](BLE_Common): 20 00 2c 00 a4 00 5f de <- 0x1818 | 0x2a63 | CPS[ CD(50.86) PW(44) ]
[ 91515][E](BLE_Common): 20 00 2e 00 a5 00 0b e3 <- 0x1818 | 0x2a63 | CPS[ CD(51.37) PW(46) ]
[ 92517][E](BLE_Common): 20 00 2c 00 a6 00 b1 e7 <- 0x1818 | 0x2a63 | CPS[ CD(51.63) PW(44) ]
[ 93004][E](Main): Shift +1 pos 1 tgt 0 min -200000000 max 200000000 r_min -2000 r_max 2000
[ 93519][E](BLE_Common): 20 00 26 00 a7 00 4e ec <- 0x1818 | 0x2a63 | CPS[ CD(52.02) PW(38) ]
[ 94521][E](BLE_Common): 20 00 20 00 a8 00 ba f0 <- 0x1818 | 0x2a63 | CPS[ CD(54.28) PW(32) ]
[ 95523][E](BLE_Common): 20 00 1e 00 a9 00 22 f5 <- 0x1818 | 0x2a63 | CPS[ CD(54.47) PW(30) ]
[ 95882][E](Main): Scanning from Check BLE Reconnect 0
[ 95883][E](BLE_Client): Scanning for BLE servers and putting them into a list...

```

doudar, 2023-01-23:
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

Yes, there is a bug there.
https://github.com/doudar/SmartSpin2k/blob/6d38d0fe76222908d80350ce1f96abf6a856a55b/src/Main.cpp#L565-L577

On line 565, one of those items should be userConfig.getConnectedHeartMonitor()
as well as on line 573

Do you want to make a PR so you get credit for it, or should I make the changes quickly?

xpectnil, 2023-01-23:
Go for it. :-)

Still not working as expected, though...

At ~ 118 W of current power and a target power of 48 Watts - nothing is happening for a minute. It doesn't shift the resistance down.
Any idea what the other problem could be?

```
[381242][E](BLE_Server): 64 02 20 01 a6 00 00 00 74 00 00 -> 0x1826 | 0x2ad2 | FTMS(IBD)[ HR(0) CD(83.00) PW(116) SD(288.00) ]
[381242][E](FTMS_SERVER): 07 -> Start Training
[381755][E](BLE_Server): 64 02 20 01 a6 00 00 00 74 00 00 -> 0x1826 | 0x2ad2 | FTMS(IBD)[ HR(0) CD(83.00) PW(116) SD(288.00) ]
[381756][E](FTMS_SERVER): 00 -> Control Request
[382264][E](BLE_Common): 20 00 76 00 a4 01 44 54 <- 0x1818 | 0x2a63 | CPS[ CD(85.57) PW(118) ]
[382267][E](BLE_Server): 64 02 2c 01 aa 00 00 00 76 00 00 -> 0x1826 | 0x2ad2 | FTMS(IBD)[ HR(0) CD(85.00) PW(118) SD(300.00) ]
[382776][E](BLE_Server): 64 02 2c 01 aa 00 00 00 76 00 00 -> 0x1826 | 0x2ad2 | FTMS(IBD)[ HR(0) CD(85.00) PW(118) SD(300.00) ]
[383278][E](BLE_Common): 20 00 72 00 a5 01 0f 57 <- 0x1818 | 0x2a63 | CPS[ CD(85.93) PW(114) ]
[383284][E](BLE_Server): 64 02 21 01 aa 00 00 00 72 00 00 -> 0x1826 | 0x2ad2 | FTMS(IBD)[ HR(0) CD(85.00) PW(114) SD(289.00) ]
[383285][E](FTMS_SERVER): 07 -> Start Training
[383672][E](PowTab): |    0|   57|  105|  134|    0|    0|    0|    0|    0|    0|    0|    0|    0|    0|    0|    0|    0|    0|    0|    0|
[383675][E](PowTab): |    0|-1256|  256| 1200|    0|    0|    0|    0|    0|    0|    0|    0|    0|    0|    0|    0|    0|    0|    0|    0|
[383796][E](BLE_Server): 64 02 21 01 aa 00 00 00 72 00 00 -> 0x1826 | 0x2ad2 | FTMS(IBD)[ HR(0) CD(85.00) PW(114) SD(289.00) ]
[383797][E](FTMS_SERVER): 00 -> Control Request
[384305][E](BLE_Common): 20 00 5c 00 a7 01 9e 5c <- 0x1818 | 0x2a63 | CPS[ CD(86.35) PW(92) ]
[384313][E](BLE_Server): 64 02 ed 00 ac 00 00 00 5c 00 00 -> 0x1826 | 0x2ad2 | FTMS(IBD)[ HR(0) CD(86.00) PW(92) SD(237.00) ]
[384817][E](BLE_Server): 64 02 ed 00 ac 00 00 00 5c 00 00 -> 0x1826 | 0x2ad2 | FTMS(IBD)[ HR(0) CD(86.00) PW(92) SD(237.00) ]
```

doudar, 2023-01-23:
If you could send a full log that would be great.
The best is if you can use Logbert https://github.com/couchcoding/Logbert/ .
Turn on the UDP logs in the settings.
Then in logbert (connected to the same network as SS2K), do Custom UDP reciever, port 10000.
Then when you're done collecting logs, put them in pastebin and post the link here.

I'll need a short ride with a few different ERG targets. Note that the ERG minimum is the min brake watts as well.

xpectnil, 2023-01-23:
Thanks for your support.

Logbert seems to be a .NET program and I've got a Mac without .NET installed.
I used the Flasher Tool and did a full log - I hope that works.

Here's 300kB of log file:
https://pastebin.com/0DF0ehpd

doudar, 2023-01-23:
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

Definitely looks like an app issue. What app is it that you're using so I can test and fix?

xpectnil, 2023-01-23:
Confirmed - it's an app issue. I just tried Zwift - works like a charm.
At least I could fix a bug along the way and contribute back to the project.

I'm had tried out TrainerDay. https://trainerday.com/  The only reason for it is that it's free in its basic version.

Any other recommendation for an App with ERG mode that works, doesn't cost that much?
I want to run some 30-60 min FTP builder track and watch videos along the way (ideally iPhone for running the ERG App so I can use my full iPad for watching videos).

Any recommendation that works really well?  No need for fancy videos or real-world simulations.

doudar, 2023-01-23:
I know @eMadman uses MyWoosh.
I'll look at trainerday and see what the issue is. I'm sure I can fix it.

eMadman, 2023-01-23:
Mywhoosh is great - completely free at this time and similarly feature rich to Zwift.  Haven't played with it in Erg but I used to do a lot of on-desk testing with it for sim mode

doudar, 2023-01-23:
If you want super simple and no install, this web app is pretty cool for erg training. I just tested it and it works.
https://flux-web.vercel.app/
https://github.com/dvmarinoff/Flux

xpectnil, 2023-01-24:
Thanks for your suggestions. I'll check them out.

xpectnil, 2023-01-27:
> Mywhoosh is great - completely free at this time and similarly feature rich to Zwift. Haven't played with it in Erg but I used to do a lot of on-desk testing with it for sim mode

Thanks, I tried it today. It's really a clone of Zwift and - unlike the App Store Reviews - ran very stable.
SS2k worked perfectly well with Mywhoosh, no problem whatsoever.

xpectnil, 2023-01-27:
One bug got fixed, the other strange behavior only happens with Trainer Day - so it seems to be an app issue, not a SS2k issue.

Closed 2023-01-27.

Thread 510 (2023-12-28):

Loss of power in sprints. (Keiser M3)

serbasan, 2023-12-28:
### Description

When I do stable training in ERG mode with power variations everything works perfectly.
When I have done a race without ERG and without SIM (I disable resistance in devices) in Zwift, using only the switches to change gears everything has worked well with powers no higher than 300W.
I have the problem when doing a sprint, going up gears with the switch reaching 400W-600W, it always drops the gears suddenly and I lose all my power. It is awful.

SmartSpin2k has very little resistance and I can no longer shift gears with the switch.

The logs say "Shift Blocked by stepper limits" and I can't shift up. I can only go down and continue going down beyond the limit many times (I hear how I reach the lower limit and the motor loses steps). After that I can go back up to the upper limit.

If I go up gears again and do a powerful Sprint, the same thing happens again.

I have also tried in SIM mode and the same thing happens.

It happened to me with the previous firmware and the new one that works with the torque table.

I have Max Bike Brake Watts set to the maximum

### Steps to reproduce

1) Start a route in SIM mode or with resistance disconnected.
2) Use the switches to up and down gears.
3) After a few minutes, go up the gears with the switch and do a 500W sprint.
4) The resistance will drop suddenly and you can no longer increase resistance with the switch.
5) Lower resistance beyond the limit many times.
6) You can now increase resistance to the limit.

**Expected behavior**
Use the switches to go up and down gears and be able to do a high-watt sprint without suddenly losing resistance.

**Actual behavior**
When I do a route in SIM mode or without resistance control connected, if I do a sprint I lose all resistance. If I try to shift up I can't and in the logs it says "Shift Blocked by stepper limits"

### Additional Information
I am using a hardware adaptation for the Keiser M3 as I have already mentioned in the [discussion section](https://github.com/doudar/SmartSpin2k/discussions/494)

[Fallo bajada de marchas.csv](https://github.com/doudar/SmartSpin2k/files/13788779/Fallo.bajada.de.marchas.csv)
[Perdida marchas sprint3.txt](https://github.com/doudar/SmartSpin2k/files/13788810/Perdida.marchas.sprint3.txt)
[Perdida marchas sprint2.txt](https://github.com/doudar/SmartSpin2k/files/13788811/Perdida.marchas.sprint2.txt)
[Perdida marchas sprint.txt](https://github.com/doudar/SmartSpin2k/files/13788812/Perdida.marchas.sprint.txt)

doudar, 2023-12-28:
You did a fantastic job collecting logs for this - Thanks!

Could you send one log from the current develop firmware with Torque Table? That would help me determine the cause much easier since there were some significant changes made to the upper boundary setting.

doudar, 2023-12-28:
Also...Looking at this more - is there any chance that the stepper motor is losing steps (slipping) when you go to higher resistance?

serbasan, 2023-12-28:
Hello.
I doubt it will lose steps since it does not require much torque to move the system, it runs very smoothly and has a very short path. I remember that I modified "driver.microsteps(8); // Set microsteps to 1/8th" to 8 steps in main.cpp
I think the problem is that my magnet system has a spring to always bring the magnet to the position of least resistance (gear 1).

There must be a moment when the firmware leaves the motor without power, perhaps during the ERG changes and the spring always pushes towards gear 1 causing a false loss of steps.

Is there a way to always keep the engine locked when changing direction?

I think this has never been a problem on the bicycles in which SmartSpin2k has been designed but on the Keizer 3M it has that difference with the spring that always pushes to gear 1

If there are any changes I can make to the firmware, compiling and testing it is no problem on my part.

How do I get a log of the firmware I have loaded?

Thank you.

doudar, 2023-12-28:
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

Set both of these to false:
https://github.com/doudar/SmartSpin2k/blob/7f2484e092204b50774cf323e30794fc34ab7fe2/src/Main.cpp#L376-L381

Remove the *.5 here:
https://github.com/doudar/SmartSpin2k/blob/7f2484e092204b50774cf323e30794fc34ab7fe2/src/Main.cpp#L452-L453

Be careful! The stepper driver might run hot after these modifications!

doudar, 2023-12-28:
As far as determining what version it's running, you can see it on boot up in the very beginning of the logs, or at the bottom of index.html.

I was able to tell it wasn't the Torque Table firmware because it's the older power table being displayed in the logs.

serbasan, 2023-12-28:
I have made the changes. I'll try as soon as possible and comment. The branch I have selected is that:

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

serbasan, 2023-12-29:
I've been testing and the loss of power when sprinting happens again.

I have removed the shift spring from the Keizer and changed the belt in a continuous loop. In this way I have canceled the force of the spring.

I have done several springs again and the problem happens but since the spring is no longer there I do not lose all the power, I simply cannot increase more resistance with the switch.
At that moment I realized that the motor loses steps so I already know what is happening:

When you do a sprint the power goes up a lot 400W-600W. At that moment the Keizer magnet exerts a lot of magnetic force and must be harder and the motor loses steps because it does not have the strength to move it.

In short, it is not a firmware error. It is due to the hardware configuration with the Keizer M3. When a lot of power is exerted (400W+) the magnet becomes very hard and the motor cannot move and loses steps. At that moment the motor is disconnected and the spring moves the magnet to the position of least resistance (gear 1).

Would it be possible for the motor to not disengage when it loses steps?

Removing the spring largely solves the problem but prevents you from being able to use the bike manually.

doudar, 2023-12-30:
Maybe reduce the size of your drive pulley to just bigger than the bolt and then put the nut at the end of the pulley instead of recessed inside it?

Or you could add another linkage to the belt (another lever) to increase the mechanical advantage.

Or, you could remix the entire SS2K case and change the gear ratio there.

serbasan, 2023-12-30:
I'll think about how to improve the transmission strength. I'm modifying the Fusion 360 box and it could do something.
With firmware modifications and adding a fan in the case it improves somewhat.
For ERG and SIM training the system works very well.

By the way, it's beside the point but since I installed the latest firmware, OTA updates no longer work for me. I have to do them by cable. The modified firmware is uploaded, it does the entire process but maintains the previous one.

For my part, this issue can be closed. It's not a firmware problem. It is a hardware problem with the Keiser M3.
When I get the modification of the tested box I will comment on it.

Thank you very much for the help.

serbasan, 2024-01-01:
Hello and Happy New Year.

I have made a hardware modification for the adaptation with Keizer.
I've gone from this:

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

To this:

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

Much more torque has been achieved and now I can do a sprint and go up gears without problems until I can't go any further.

I will continue training and adjusting the STL of the box and adapter until I am convinced that everything fits.
With each change I get it to work better. I'm very excited.

Can I make STLs public on this Github project and on platforms like Thingiverse?

doudar, 2024-01-01:
Awesome! That was a fast fix!

Yes, if you'd like, you can contribute the hardware mod back here. I'd love to add it to the repo so others can use it if they wish. I don't have any issues with thingaverse either.

Happy new year!

eMadman, 2024-01-01:
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

Awesome that you have it working!

Just ensure you're using gpl version 2 when you post it to thingiverse or others!

It would also be awesome to have it in the repo here as a mod!

doudar, 2024-03-23:
Curious if you we able to solve this. There have been a few people asking on the Facebook group about the M3

serbasan, 2024-03-23:
Hello.
With the modifications I made to the SmartSpinv2 box and the top torque adapter for the Keizer M3 gears everything works perfectly. I've been using it for several months now and I had already forgotten all the time I spent adapting everything to the Keizer M3. When I do my workouts I turn it on, use it and everything works perfectly. I really enjoy how well it works.

The only thing you have to keep in mind is that I use SmartSpin2k together with [another project](https://github.com/ajs123/KBikeBLE) to be able to get power and cadence via Bluetooth, so it may be a little more complex for Keizer M3 users, but it works so well that I recommend the effort.

Maybe it can only be used with heart rate as discussed here.

The files I have designed [are these](https://www.thingiverse.com/thing:6545641).

This modification is part of version 2 since I have assembled it myself by purchasing the v2 board. The box is attached with the version of the inserts for the screws.
There is a version to mount a fan.
Everything is secured with a front flange and the two 3d fasteners. Everything is well secured like this.

You can take all the files and add them to your repository if you wish and if you have questions or want me to make any modifications, you can tell me.

Thank you very much for everything and it would be a great honor if someone can take advantage of it for their Keizer M3.

Greetings.

doudar, 2024-03-23:
That's pretty awesome! Any chance you have Facebook or could make an intructable (https://www.instructables.com/) for it? I know a lot of Keiser users are interested.

Closed 2025-01-24.

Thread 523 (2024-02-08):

[BUG] Uncontrollable Upward Shifting

cjwhitedev, 2024-02-08:
### Description

Whenever I try to use my smartspin it shifts uncontrollably upward.

### Steps to reproduce

1. Turn on unit
2. Shift the unit from any source (the web interface or via swift)
3. It will now shift updward indefinitely.

Please reference my comments in #504.

[Custom UDP Receiver (Port 10000).txt](https://github.com/doudar/SmartSpin2k/files/14211589/Custom.UDP.Receiver.Port.10000.txt)

cjwhitedev, 2024-02-08:
What do you mean by disconnected? If it is not attached to zwift?

doudar, 2024-02-08:
Physically disconnecting the shifter buttons. I'm thinking this is some type of hardware issue or possibly the shifter wires inside the case are in close proximity to the stepper wires (like caught together in the case seam)

cjwhitedev, 2024-02-08:
Its been unplugged for a couple weeks. I just plugged in the power, nothing else, and it resumed climbing indefinitely. I let it run for a few seconds before unplugging it again. Here is that log.
[Custom UDP Receiver 2 (Port 10000).txt](https://github.com/doudar/SmartSpin2k/files/14212081/Custom.UDP.Receiver.2.Port.10000.txt)

doudar, 2024-02-08:
That was shifting without any input from you? Gotta be some type of hardware issue.

cjwhitedev, 2024-02-08:
I have the latest release installed. This is where i bought it from:
https://www.etsy.com/listing/1356903775/smartspin2k-v3-spin-bike-smart-trainer

eMadman, 2024-02-08:
Just want to confirm that the shifter and its cable were disconnected from the breakout cable during this test - I want to make sure it's not a hardware issue relating to the shifter before I ask you to open up the unit.

There's a small possibility that the motor's cable is twisted around the internal wiring causing some interference

cjwhitedev, 2024-02-09:
The only thing plugged in was the power. I will open the unit up later and report back.

eMadman, 2024-02-09:
> The only thing plugged in was the power. I will open the unit up later and report back.

Sounds good.  We have a PDF manual for assembly/disassembly here: https://www.smartspin2k.com/diy-building-instructions - the most fiddly part is routing the cable internally but it should be pretty straightforward

cjwhitedev, 2024-02-09:
Nothing in here looks tangled or twisted in here to me.

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

eMadman, 2024-02-11:
Ahh!  it's a V2!  My best guess, this might be an issue with the 3.5mm headphone connector or a failure on the PCB.

Can you email me at emadmanmakes@gmail.com?  I think we can work something out since you bought this from me last year.

doudar, 2024-02-24:
Did we ever figure out what the (hardware?) issue was here?

eMadman, 2024-02-25:
@doudar - the v3 upgrade kit sorted the issue out.  Pretty sure it's something wrong with the old circuit board.  The pic looks like it was from my last batch of esp32s before the transition when I had to start soldering that offshoot capacitor into place or they wouldn't accept firmware properly.

doudar, 2024-02-25:
Okay! Thx closing this then.

Closed 2024-02-25.

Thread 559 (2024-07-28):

[BUG] Unable to mount LittleFS after flashing firmware on new PCB, mounts fine after re-flashing with mobile app instead.

jrbarrick, 2024-07-28:
<!--
Do you want to ask a question? Are you looking for support? Please don't post here. Instead please use the discussion page instead at https://github.com/doudar/SmartSpin2k/discussions

Type your responses after the bolded description, steps to reproduce and behavior tags.
-->
### Description

Unable to mount LittleFS after flashing firmware on new PCB, mounts fine after re-flashing with mobile app.  Reproduced on 3 new PCBs.  Once the issue is fixed by flashing with the mobile app, flashing later on over USB works fine.

### Steps to reproduce

1. Flashed latest firmware (24.7.9) to ESP32 over USB using the SmartSpin2kFlasher tool.  Flash reports that it works fine and hashes verify. Device reboots fine, however errors are thrown related to LittleFS:
```
Using 'COM12' as serial port.
Connecting.....
Detecting chip type... Unsupported detection protocol, switching and trying again...
Connecting..........
Detecting chip type... ESP32
Connecting....

Chip Info:
 - Chip Family: ESP32
 - Chip Model: ESP32-D0WD (revision 1)
 - Number of Cores: 2
 - Max CPU Frequency: 240MHz
 - Has Bluetooth: YES
 - Has Embedded Flash: NO
 - Has Factory-Calibrated ADC: YES
 - MAC Address: A0:A3:B3:79:88:48
Uploading stub...
Running stub...
Stub running...
Changing baud rate to 460800
Changed.
 - Flash Size: 4MB
 - Flash Mode: dio
 - Flash Frequency: 40MHz
Flash will be erased from 0x00001000 to 0x00004fff...
Flash will be erased from 0x00008000 to 0x00008fff...
Flash will be erased from 0x0000e000 to 0x0000ffff...
Flash will be erased from 0x00010000 to 0x001adfff...
Compressed 15872 bytes to 10319...
Writing at 0x00001000... (100 %)
Wrote 15872 bytes (10319 compressed) at 0x00001000 in 0.6 seconds (effective 230.0 kbit/s)...
Hash of data verified.
Compressed 3072 bytes to 146...
Writing at 0x00008000... (100 %)
Wrote 3072 bytes (146 compressed) at 0x00008000 in 0.1 seconds (effective 313.3 kbit/s)...
Hash of data verified.
Compressed 8192 bytes to 47...
Writing at 0x0000e000... (100 %)
Wrote 8192 bytes (47 compressed) at 0x0000e000 in 0.1 seconds (effective 442.3 kbit/s)...
Hash of data verified.
Compressed 1693792 bytes to 1034329...
Writing at 0x00010000... (1 %)
...
Writing at 0x001acb9e... (100 %)
Wrote 1693792 bytes (1034329 compressed) at 0x00010000 in 26.6 seconds (effective 509.8 kbit/s)...
Hash of data verified.

Leaving...
Hard Resetting...
Hard resetting via RTS pin...
Done! Flashing is complete!

Showing logs:
[15:14:10][    30][E](Main): Compiled Apr 28 202401:49:10
[15:14:10][    31][E](Main): Current Board Revision is: Revision Two
[15:14:10][    33][E](Main): Mounting Filesystem
[15:14:10]./components/esp_littlefs/src/littlefs/lfs.c:1229:error: Corrupted dir pair at {0x0, 0x1}
[15:14:10]E (28) esp_littlefs: mount failed,  (-84)
[15:14:10]E (28) esp_littlefs: Failed to initialize LittleFS
[15:14:10][    36][E][LittleFS.cpp:95] begin(): Mounting LittleFS failed! Error: -1
[15:14:10][    38][E](Main): An Error has occurred while mounting LittleFS.
[15:14:10][    41][E](FS_Upgrader): Stopping LittleFS
[15:14:10]E (34) SPIFFS: mount failed, -10025
[15:14:10][    42][E][SPIFFS.cpp:89] begin(): Mounting SPIFFS failed! Error: -1
[15:14:10][    42][E](FS_Upgrader): SPIFFS Not Found - Could not upgrade FS
[15:14:10]./components/esp_littlefs/src/littlefs/lfs.c:1229:error: Corrupted dir pair at {0x0, 0x1}
[15:14:10]E (139) esp_littlefs: mount failed,  (-84)
[15:14:10]E (139) esp_littlefs: Failed to initialize LittleFS
[15:14:11][   653][E](Config): Reading File: /config.txt
[15:14:11][   655][E][vfs_api.cpp:105] open(): /littlefs/config.txt does not exist, no permits for creation
[15:14:11][   655][E](Config): Couldn't find configuration file.
[15:14:11][   658][E](Config): Contents of file: /config.txt
[15:14:11][   659][E][vfs_api.cpp:105] open(): /littlefs/config.txt does not exist, no permits for creation
[15:14:11][   659][E](Config): Failed to read file
[15:14:11][   662][E][vfs_api.cpp:182] remove(): /config.txt does not exists or is directory
[15:14:11][   663][E](Config): Writing File: /config.txt
[15:14:11][   678][E](Config): Reading File: /userPWC.txt
[15:14:11][   681][E][vfs_api.cpp:105] open(): /littlefs/userPWC.txt does not exist, no permits for creation
[15:14:11][   682][E](Config): Couldn't find configuration file. Loading Defaults
[15:14:11][   684][E](Config): Contents of file: /userPWC.txt
[15:14:11][   687][E][vfs_api.cpp:105] open(): /littlefs/userPWC.txt does not exist, no permits for creation
[15:14:11][   687][E](Config): Failed to read file
[15:14:11][   692][E][vfs_api.cpp:182] remove(): /userPWC.txt does not exists or is directory
[15:14:11][   692][E](Config): Writing File: /userPWC.txt
```
3. Can connect just fine with BT, and app connects to device fine.  Settings can be "saved" in the app, however they aren't saved and are lost at reboot.
4. Can retry flashing firmware over USB with no change, and also tried 24.4.28 over USB.
5. However, flashing 24.4.28 using the Firmware Update option in the mobile app seems to work different, as partition mounts fine when rebooting after flash using the app, and settings can be saved without any issues:
```
[15:17:39]1. BeginOTA2. Running partition type 0 subtype 16 (offset 0x00010000)
[15:17:39]3. Writing to partition subtype 17 at offset 0x1f0000
...
[15:20:20]..................................................................................4. Final byte arrivedSet Boot partionRestarting...
[15:20:20][    31][E](Main): Current Board Revision is: Revision Two
[15:20:20][    33][E](Main): Mounting Filesystem
[15:20:20][    38][E](Config): Reading File: /config.txt
[15:20:20][    60][E](Config): Config File Loaded: /config.txt
[15:20:20][    61][E](Config): Contents of file: /config.txt
[15:20:20][    86][E](Config): Writing File: /config.txt
[15:20:20][   110][E](Config): Reading File: /userPWC.txt
[15:20:20][   135][E](Config): Config File Loaded: /userPWC.txt
[15:20:20][   135][E](Config): Contents of file: /userPWC.txt
[15:20:20][   171][E](Config): Writing File: /userPWC.txt
```

**Expected behavior**
Firmware boots and mounts LittleFS

**Actual behavior**
Firmware boots and fails to mount LittleFS

### Additional Information
Full log:
https://pastebin.com/eMT0VqZS

doudar, 2024-07-28:
This might be more of an issue with documentation.

On initial installs, in PlatformIO, you need to select "upload file system image" as well.

The upgrade probably works because there's a littlefs.format() in order to fix errors like this.

In new branches I removed the spiffs upgrader (firmwares that were over two years old used spiffs). Instead of the upgrader, I suppose I could place a format()  on boot if the files cannot be accessed.

Thanks for the report!

jrbarrick, 2024-07-28:
Read the LittleFS docs a bit as well, looks like you can just call LittleFS.begin(true) instead of LittleFS.begin(false) and it will format the LittleFS partition if it doesn't exist.  Did some testing on my end and it seems like that does the trick.

doudar, 2024-07-28:
I'm guessing it was set to (false) previously for the upgrade logic to work correctly. I think for now I slightly prefer keeping the format() inside of the if statement, just for readability.

I'd love any more insight you might have! Thanks for the help!

Closed 2024-07-28.

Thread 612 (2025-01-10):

Resets during ERG training with power changes

serbasan, 2025-01-10:
I've noticed an issue where I experience resets during ERG mode training sessions. This usually happens when there’s a significant power change, for example, going from 115W to 245W.

In a 1-hour session, this can occur between 0 to 3 times. Today, I was finally able to capture a log of the issue since it happened while my computer was on.

The reset occurred around line 12000 in the attached log.
Additionally, I noticed that the PowerTable was emptied at line 11278, which might be related.
This issue has been happening for weeks, but I hadn’t been able to capture it until now.

Attachments:

Log file with the reset moment. (**version 24.12.8**)
Thank you in advance for your time and help in investigating this issue.

[Custom UDP Receiver (Port 10000).csv](https://github.com/user-attachments/files/18381807/Custom.UDP.Receiver.Port.10000.csv)

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

doudar, 2025-01-12:
I ride ERG a lot and haven't been seeing any reboots. I looked at your log, there's a reboot. Looking at this, It's having a hard time creating anything much for the power table. That still shouldn't cause a reboot, but it might be what's exacerbating it. My guess is what's actually causing a reboot is an insane number being returned from one of the lookup functions. I'll look into adding more protections there.

In the meantime, I'd recommend you (Clear active powertable using the app first) give homing a try on your bike. Select the calibrate button on any training app, start pedaling and let the knob go to it's limits. Once it starts moving, you can stop pedaling and let it do it's thing. Once you enable homing, then on every power cycle, the SmartSpin2k will seek to the lowest resistance position on your bike as soon as you start pedaling. Pressing a shifter before or during pedaling will abort the procedure. You can deactivate homing by doing "clear active powertable" using the app.

Edit: Also, I just remembered that you have a bit of a custom bike setup that requires very small movements to change power. That's why the power table is having a hard time in your case, because the numbers are similar. You use very low shift steps, correct? Try increasing the number here (to 8 or maybe even 16) and let me know if it helps. https://github.com/doudar/SmartSpin2k/blob/705b7d203deda7e61de0b8e416747a2f415efc47/src/Main.cpp#L559

serbasan, 2025-01-12:
Hi Anthony,

Thank you for suggesting increasing the Steps to 16. I've tested this configuration and attached two logs for your review:

Calibration log:
I captured this log during calibration from Zwift after clearing the PowerTable. However, I don’t see the behavior you mentioned about reaching the lower and upper limits during calibration. The values only move slightly at times. Similarly, nothing unusual happens when I start SS2K and begin pedaling.

ERG test log:
This log corresponds to a test training session in ERG mode. Could you check if the PowerTable now looks appropriate with 16 Steps?

Thank you for your help and support!

Attachments:

Calibration log
ERG test log
[Calibracion 16steps.csv](https://github.com/user-attachments/files/18388971/Calibracion.16steps.csv)
[erg 16steps.csv](https://github.com/user-attachments/files/18388972/erg.16steps.csv)

serbasan, 2025-01-12:
Hi Anthony,

Following up on the issue with homing that I mentioned earlier, I noticed in the documentation that the SS2K version 2 uses a TMC2225 driver, while version 3 seems to include a TMC2209 or a similar driver.

Could this difference be the reason why the homing function isn’t available on the v2?
If so, would it be possible to replace the TMC2225 with a TMC2209 on the v2 to enable this feature?

Thanks for your help and for the great work on this project.

Best regards,

doudar, 2025-01-12:
Okay, yes the 2225 doesn't support sensorless homing. I didn't realize you were using a version 2. In addition to using a 2209, You would also need to look at boards.h and settings.h and add the version resistor and make all of your connections the same as version 3, as some of the pins changed.

doudar, 2025-01-14:
It would enable homing, otherwise, there's no change. I'm not sure how homing would work on your bike either because of the constant pull - it might false trigger the high limit prematurely, but you might be able to increase homing force enough to compensate for that. I'm glad that you were able to get this going!

Closed 2025-01-24.

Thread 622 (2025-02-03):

[BUG] Motor went past lowest bike resistance

madxime, 2025-02-03:
<!--
Do you want to ask a question? Are you looking for support? Please don't post here. Instead please use the discussion page instead at https://github.com/doudar/SmartSpin2k/discussions

Type your responses after the bolded description, steps to reproduce and behavior tags.
-->
### Description

<!-- Description of the bug -->
I was doing a workout in Rouvy where the goal was to keep a 85 RPM cadence with 120 RPM 15 seconds bursts. When I reached the first burst, the bike resistance dropped almost instantly when I started spinning faster, and the motor kept turning past the minimum resistance of the bike's knob which broke the internal spur gear (i.e. this one: https://github.com/doudar/SmartSpin2k/blob/develop/Hardware/Common%20Assets/Gears/Spur%20gear%201M%2011T.STL)

### Steps to reproduce

I don't know

**Expected behavior**
The resistance shouldn't decrease or increase past some failsafe value

**Actual behavior**
The resistance went past the bike's minimum resistance value

### Additional Information
I was using an IC Bike SE with smartspin2k version [25.1.10](https://github.com/doudar/SmartSpin2k/releases/tag/25.1.10). I had kept all the default tuning values. If that can be useful, I noticed that my bike's minimum reported resistance is 1 when the knob is set to the lowest value, not 0.

Is there something I should've tuned that would've prevented this issue from happening?

jekkos, 2025-04-02:
I had similar issue when using erg, of has been quite unreliable.for me. Is there any way to calibrate the trainer not to go below a certain value?

doudar, 2025-04-02:
If you have a bike with defined mechanical stops, (and you're using an R3 SS2k), you can "calibrate trainer" in any app and the SS2k will find the travel limits of the knob and respect them. You'll probably want to use the SmartSpin2k companion app and "clear existing power table" first.

There's a lot of work going on in the testing branch to improve related things, we're in code cleanup and bug fixing stage on the testing branch and it's not fully stable yet.

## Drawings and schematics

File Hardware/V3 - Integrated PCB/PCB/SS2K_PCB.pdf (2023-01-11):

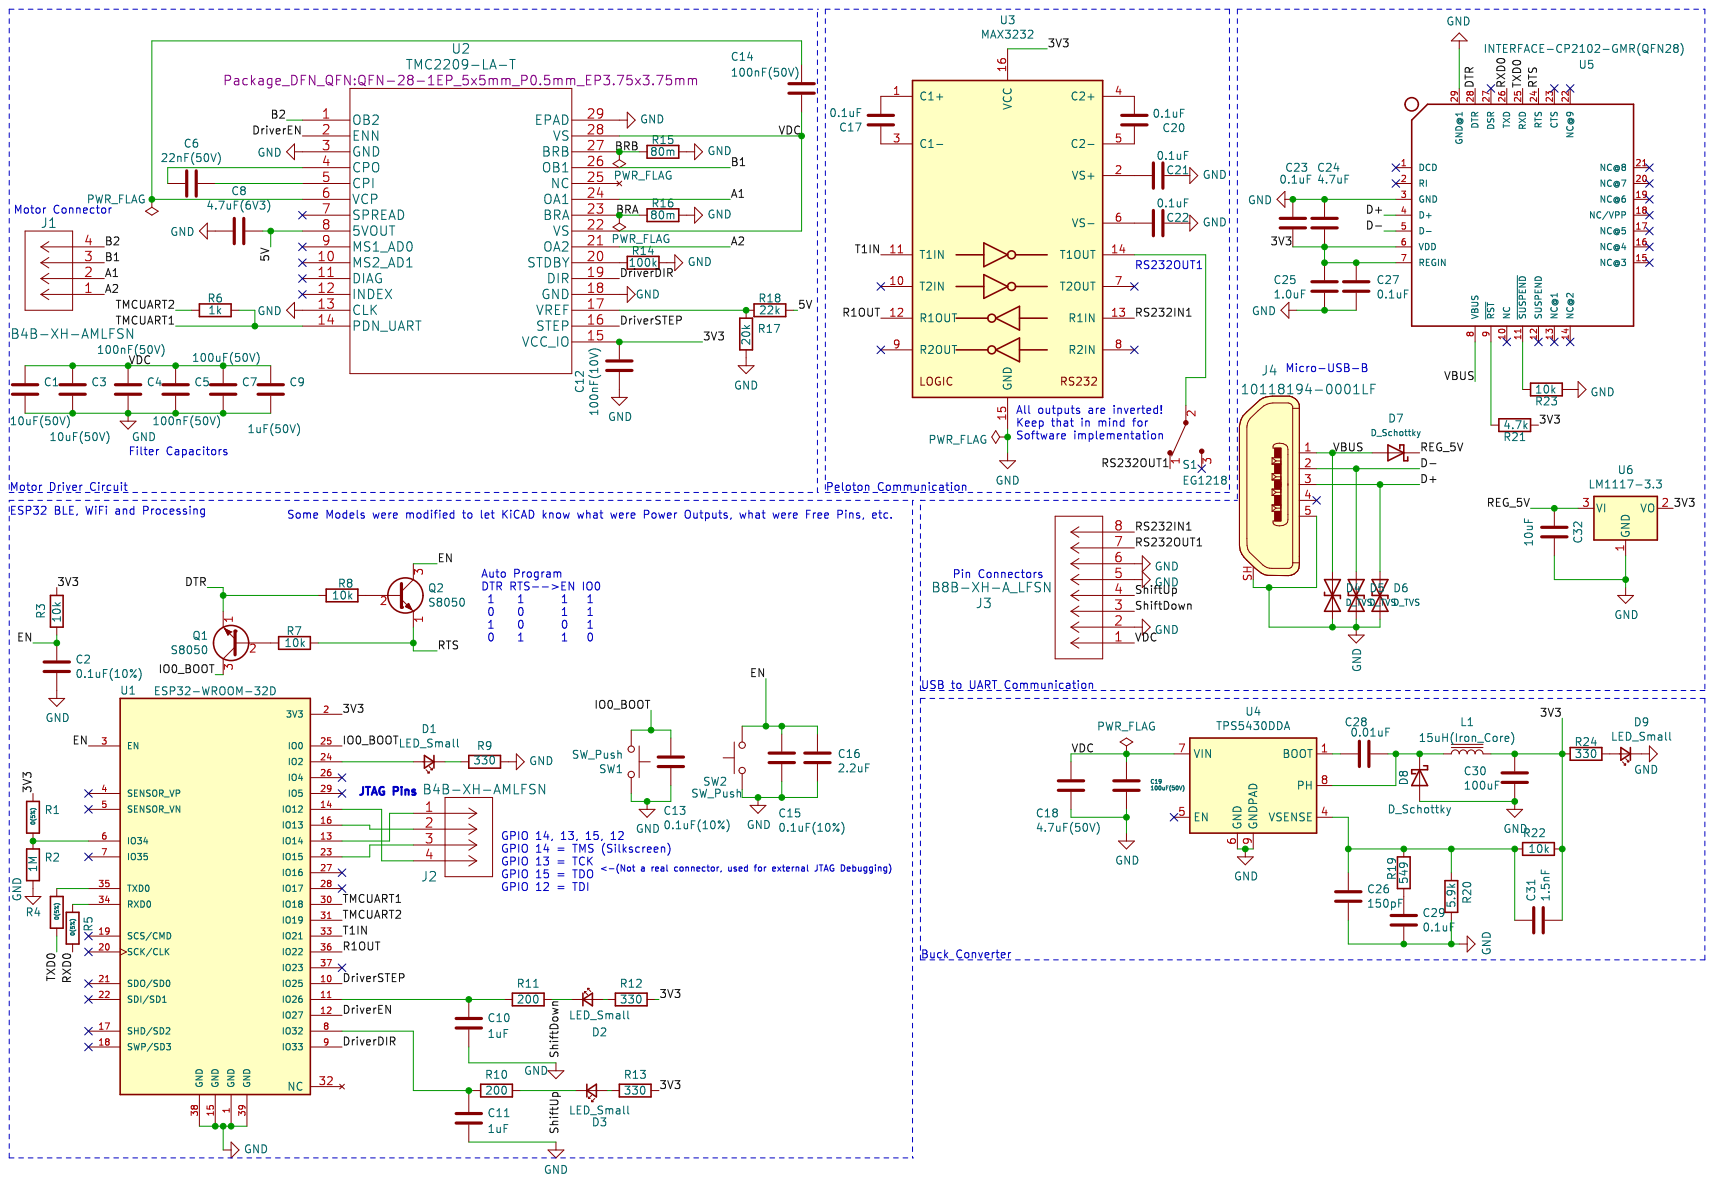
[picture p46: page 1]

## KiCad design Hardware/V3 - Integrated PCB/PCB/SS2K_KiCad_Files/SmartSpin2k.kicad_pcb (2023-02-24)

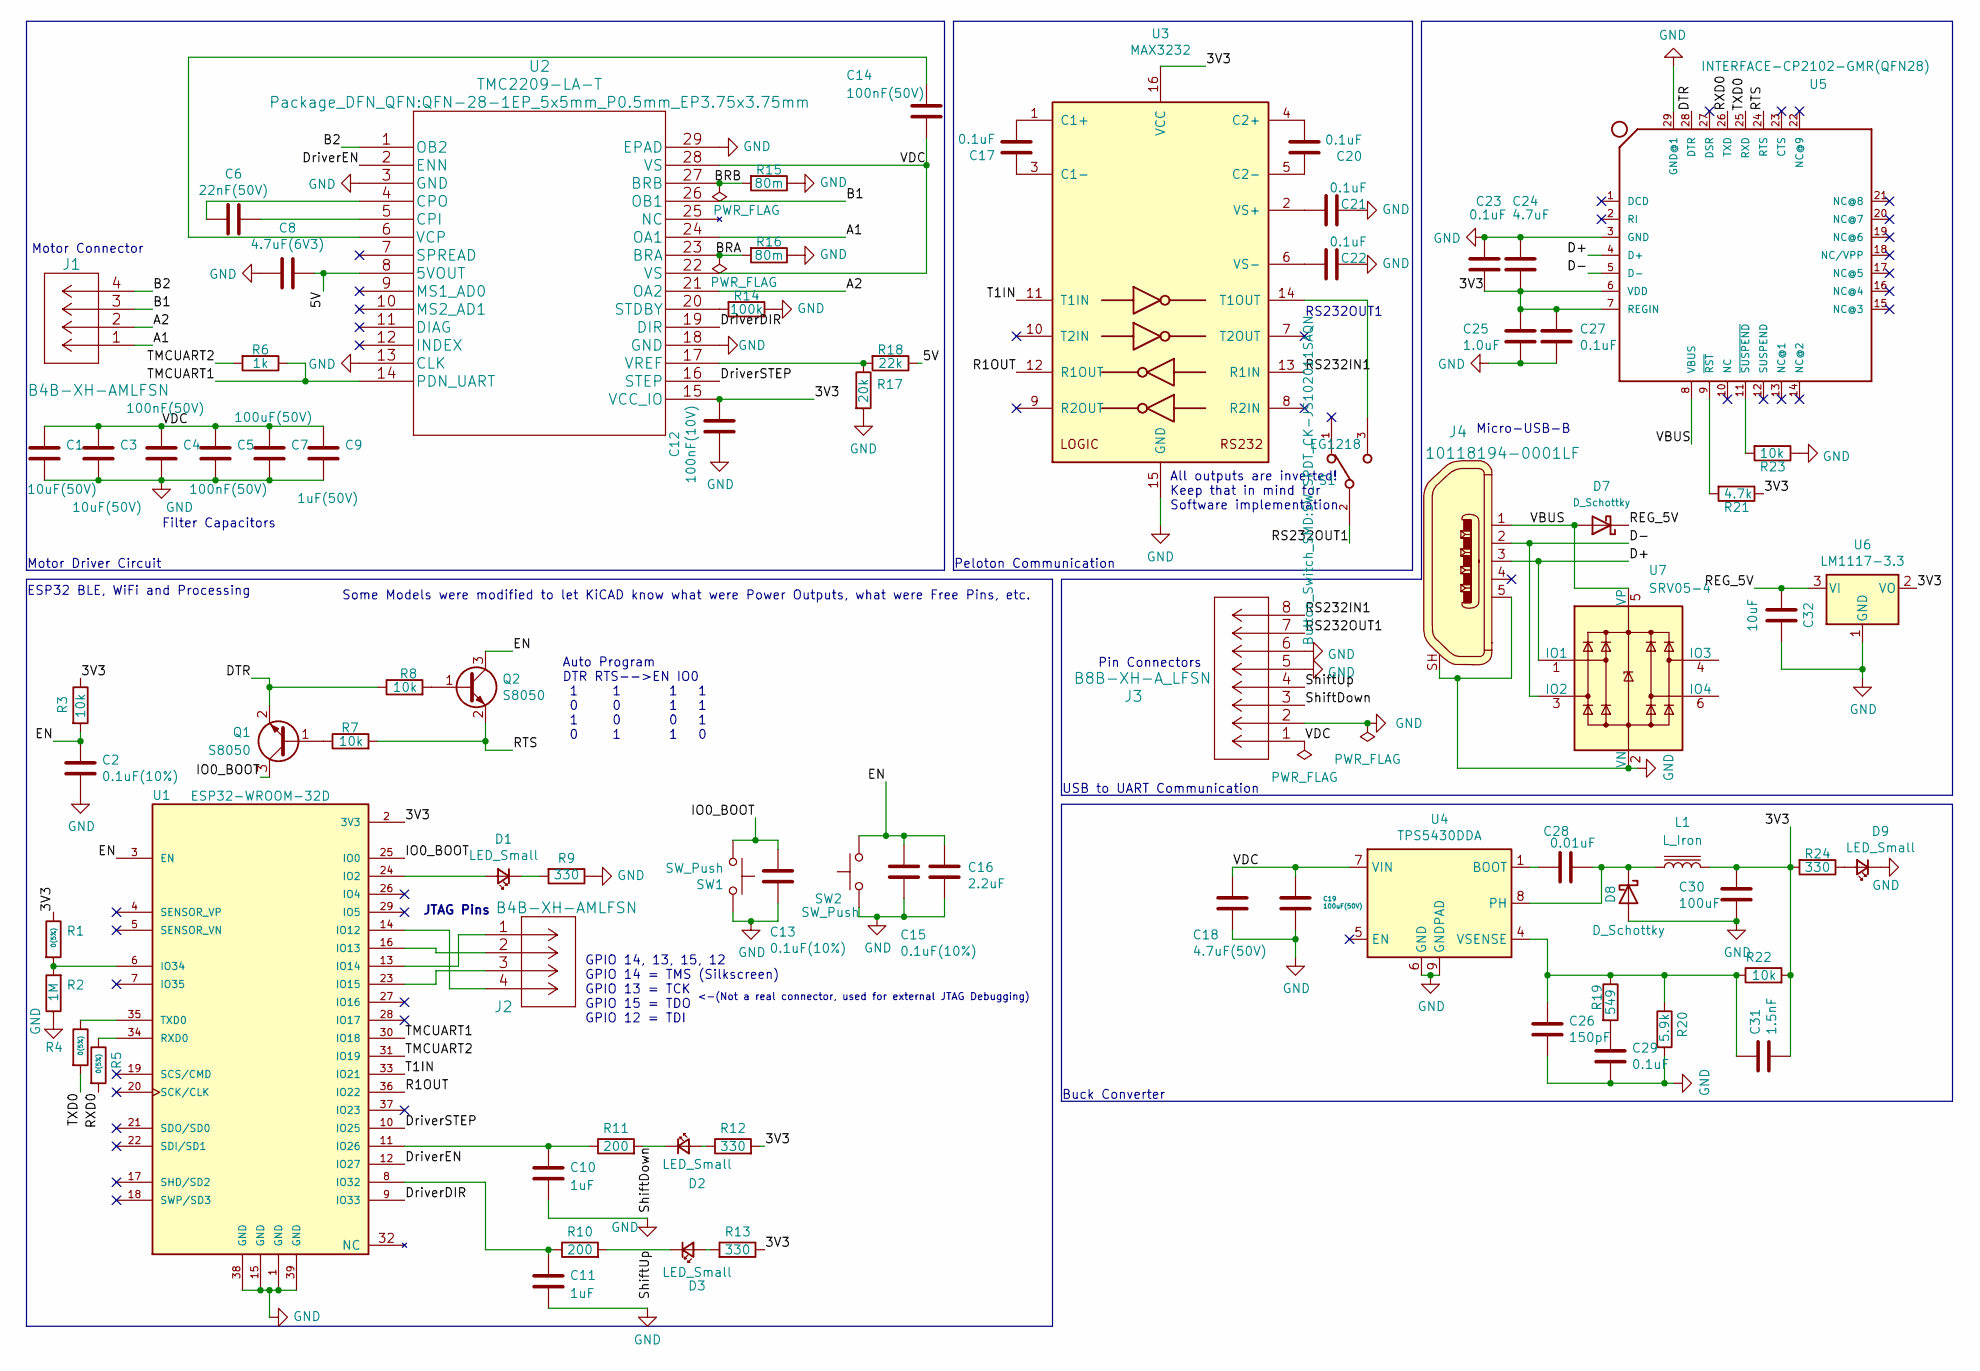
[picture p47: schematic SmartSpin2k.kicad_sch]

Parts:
C1: 10uF(50V); C_0805_2012Metric
C2, C13, C15: 0.1uF(10%); C_0402_1005Metric
C3: 10uF(50V); C_1206_3216Metric
C4, C5, C14: 100nF(50V); C_0805_2012Metric
C6: 22nF(50V); C_0805_2012Metric
C7, C19: 100uF(50V); CP_Elec_8x10
C8: 4.7uF(6V3); C_0805_2012Metric
C9: 1uF(50V); C_0603_1608Metric
C10, C11: 1uF; C_0603_1608Metric
C12: 100nF(10V); C_0805_2012Metric
C16: 2.2uF; C_0402_1005Metric
C17, C20, C21, C22, C23, C27, C29: 0.1uF; C_0402_1005Metric
C18: 4.7uF(50V); C_1206_3216Metric
C24: 4.7uF; C_0805_2012Metric
C25: 1.0uF; C_0805_2012Metric
C26: 150pF; C_0805_2012Metric
C28: 0.01uF; C_0805_2012Metric
C30: 100uF; C_1206_3216Metric
C31: 1.5nF; C_0805_2012Metric
C32: 10uF; C_0603_1608Metric
D1, D2, D3, D9: LED_Small; LED_0603_1608Metric
D7, D8: D_Schottky; D_SMA
J1, J2: B4B-XH-AMLFSN; JST_XH_B4B-XH-AM_1x04_P2.50mm_Vertical
J3: B8B-XH-A_LFSN; JST_XH_B8B-XH-AM_1x08_P2.50mm_Vertical
J4: 10118194-0001LF; USB_Micro_B_Female_10118194-0001LF; MPN 10118194-0001LF; Digi-Key_PN 609-4618-1-ND
L1: L_Iron; L_12x12mm_H8mm
Q1, Q2: S8050; SOT-23
R1, R4, R5: 0(5%); R_0402_1005Metric
R2: 1M; R_0402_1005Metric
R3, R7, R8, R22, R23: 10k; R_0402_1005Metric
R6: 1k; R_0402_1005Metric
R9, R12, R13, R24: 330; R_0402_1005Metric
R10, R11: 200; R_0402_1005Metric
R14: 100k; R_0402_1005Metric
R15, R16: 80m; R_1206_3216Metric
R17: 20k; R_0805_2012Metric
R18: 22k; R_0402_1005Metric
R19: 549; R_0402_1005Metric
R20: 5.9k; R_0603_1608Metric
R21: 4.7k; R_0402_1005Metric
S1: EG1218; SW_SPDT_CK-JS102011SAQN
SW1, SW2: SW_Push; SW_Push_SPST_NO_Alps_SKRK
U1: ESP32-WROOM-32D; ESP32-WROOM-32; PARTREV 1.9
U2: TMC2209-LA-T; QFN-28-1EP_5x5mm_P0.5mm_EP3.75x3.75mm
U3: MAX3232; MAX3232IPWR
U4: TPS5430DDA; SOIC-8-1EP_3.9x4.9mm_P1.27mm_EP2.514x3.2mm
U5: INTERFACE-CP2102-GMR(QFN28); QFN-28-1EP_5x5mm_P0.5mm_EP3.35x3.35mm; MPN CP2102-GMR
U6: LM1117-3.3; SOT-223-3_TabPin2
U7: SRV05-4; SOT-23-6

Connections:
/3V3: C12.1, C23.1, C24.2, C25.1, C27.1, C30.1, C31.2, L1.2, R1.1, R3.1, R12.2, R13.1, R21.1, R22.2, R24.2, U1.2 (3V3), U2.15 (VCC_IO), U3.16 (VCC), U5.6 (VDD), U5.7 (REGIN), U6.2 (VO)
/5V: C8.1, R18.1, U2.8 (5VOUT)
/A1: J1.1, U2.24 (OA1)
/A2: J1.2, U2.21 (OA2)
/B1: J1.3, U2.26 (OB1)
/B2: J1.4, U2.1 (OB2)
/BRA: R16.2, U2.23 (BRA)
/BRB: R15.2, U2.27 (BRB)
/D+: J4.3, U5.4 (D+), U7.1 (IO1)
/D-: J4.2, U5.5 (D-), U7.3 (IO2)
/DTR: Q1.2 (E), R8.1, U5.28 (DTR)
/DriverDIR: U1.9 (IO33), U2.19 (DIR)
/DriverEN: U1.12 (IO27), U2.2 (ENN)
/DriverSTEP: U1.10 (IO25), U2.16 (STEP)
/EN: C2.1, C15.1, C16.1, Q2.3 (C), R3.2, SW2.2, U1.3 (EN)
/IO0_BOOT: C13.1, Q1.3 (C), SW1.1, U1.25 (IO0)
/R1OUT: U1.36 (IO22), U3.12 (R1OUT)
/REG_5V: C32.2, D7.1 (K), U6.3 (VI)
/RS232IN1: J3.8, U3.13 (R1IN)
/RS232OUT1: J3.7, S1.2
/RTS: Q2.2 (E), R7.2, U5.24 (RTS)
/RXD0: R5.2, U5.26 (TXD)
/ShiftDown: D2.1 (K), J3.3, R11.2
/ShiftUp: D3.1 (K), J3.4, R10.2
/T1IN: U1.33 (IO21), U3.11 (T1IN)
/TMCUART1: R6.1, U1.30 (IO18), U2.14 (PDN_UART)
/TMCUART2: R6.2, U1.31 (IO19)
/TXD0: R4.2, U5.25 (RXD)
/VBUS: D7.2 (A), J4.1, U5.8 (VBUS), U7.5 (VP)
/VDC: C1.1, C3.1, C4.1, C5.1, C7.1, C9.1, C14.1, C18.1, C19.1, J3.1, U2.22 (VS), U2.28 (VS), U4.7 (VIN)
GND: C1.2, C2.2, C3.2, C4.2, C5.2, C7.2, C8.2, C9.2, C10.2, C11.2, C12.2, C13.2, C15.2, C16.2, C18.2, C19.2, C21.2, C22.2, C23.2, C24.1, C25.2, C26.2, C27.2, C29.2, C30.2, C32.1, D8.2 (A), D9.1 (K), J3.2, J3.5, J3.6, J4.5, J4.SH, R2.1, R9.1, R14.1, R15.1, R16.1, R17.2, R20.2, R23.1, SW1.2, SW2.1, U1.1 (GND), U1.15 (GND), U1.38 (GND), U1.39 (GND), U2.3 (GND), U2.13 (CLK), U2.18 (GND), U2.29 (EPAD), U3.15 (GND), U4.6 (GND), U4.9 (GNDPAD), U5.3 (GND), U5.29 (GND@1), U6.1 (GND), U7.2 (VN)
unnamed: C6.1, U2.5 (CPI)
unnamed: C6.2, U2.4 (CPO)
unnamed: C10.1, R11.1, U1.11 (IO26)
unnamed: C11.1, R10.1, U1.8 (IO32)
unnamed: C14.2, U2.6 (VCP)
unnamed: C17.1, U3.3 (C1-)
unnamed: C17.2, U3.1 (C1+)
unnamed: C20.1, U3.5 (C2-)
unnamed: C20.2, U3.4 (C2+)
unnamed: C21.1, U3.2 (VS+)
unnamed: C22.1, U3.6 (VS-)
unnamed: C26.1, C31.1, R19.1, R20.1, R22.1, U4.4 (VSENSE)
unnamed: C28.1, U4.1 (BOOT)
unnamed: C28.2, D8.1 (K), L1.1, U4.8 (PH)
unnamed: C29.1, R19.2
unnamed: D1.1 (K), R9.2
unnamed: D1.2 (A), U1.24 (IO2)
unnamed: D2.2 (A), R12.1
unnamed: D3.2 (A), R13.2
unnamed: D9.2 (A), R24.1
unnamed: J2.1, U1.13 (IO14)
unnamed: J2.2, U1.16 (IO13)
unnamed: J2.3, U1.23 (IO15)
unnamed: J2.4, U1.14 (IO12)
unnamed: Q1.1 (B), R7.1
unnamed: Q2.1 (B), R8.2
unnamed: R1.2, R2.2, U1.6 (IO34)
unnamed: R4.1, U1.35 (TXD0)
unnamed: R5.1, U1.34 (RXD0)
unnamed: R14.2, U2.20 (STDBY)
unnamed: R17.1, R18.2, U2.17 (VREF)
unnamed: R21.2, U5.9 (~RST)
unnamed: R23.2, U5.11 (~SUSPEND)
unnamed: S1.3, U3.14 (T1OUT)

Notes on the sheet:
Peloton Communication
JTAG Pins
Motor Connector
Buck Converter
ESP32 BLE, WiFi and Processing
RS232OUT1
USB to UART Communication
Pin Connectors
All outputs are inverted! Keep that in mind for Software implementation
<-(Not a real connector, used for external JTAG Debugging)
Some Models were modified to let KiCAD know what were Power Outputs, what were Free Pins, etc.
Auto Program DTR RTS-->EN IO0 1 1 1 1 0 0 1 1 1 0 0 1 0 1 1 0
GPIO 14, 13, 15, 12 GPIO 14 = TMS (Silkscreen) GPIO 13 = TCK GPIO 15 = TDO GPIO 12 = TDI
Motor Driver Circuit
Filter Capacitors
Micro-USB-B

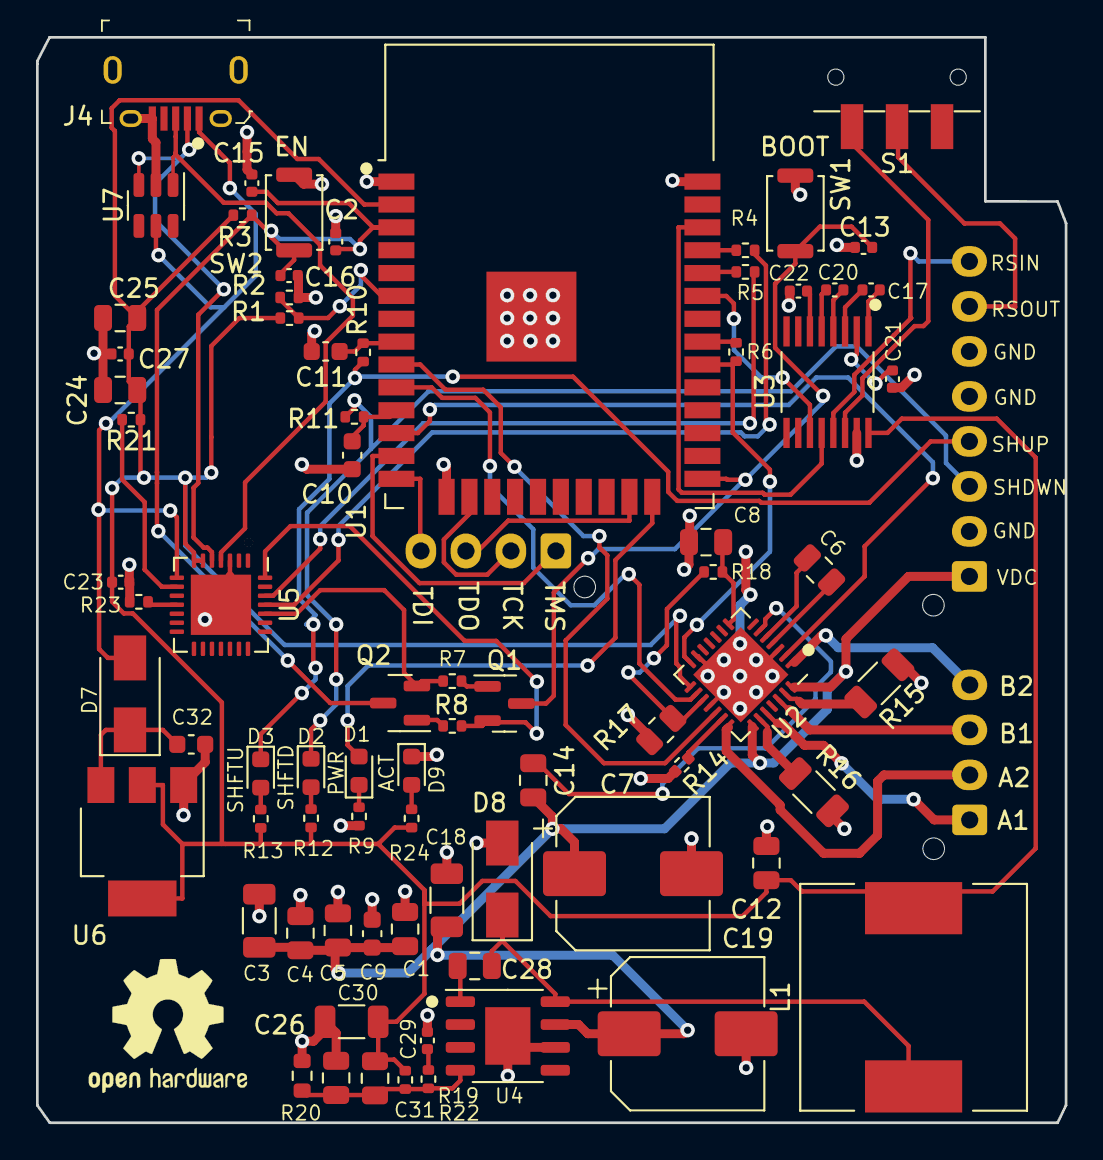
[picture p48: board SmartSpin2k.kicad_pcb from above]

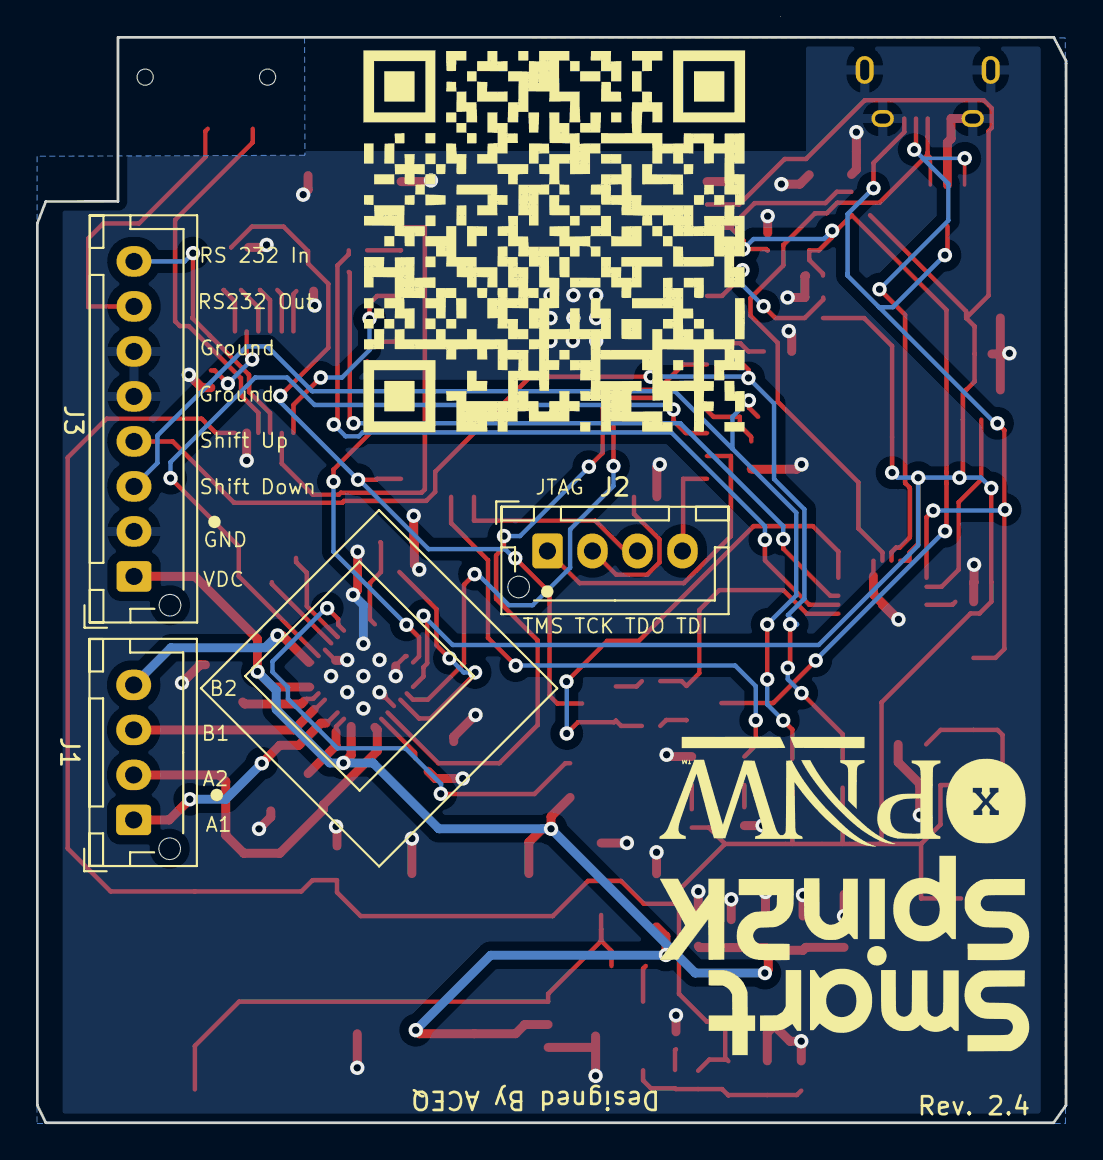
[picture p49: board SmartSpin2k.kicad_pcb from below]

Board: 2 copper layers, 57.2 x 60.3 mm, 79 parts (3 on the bottom side), 65 nets.

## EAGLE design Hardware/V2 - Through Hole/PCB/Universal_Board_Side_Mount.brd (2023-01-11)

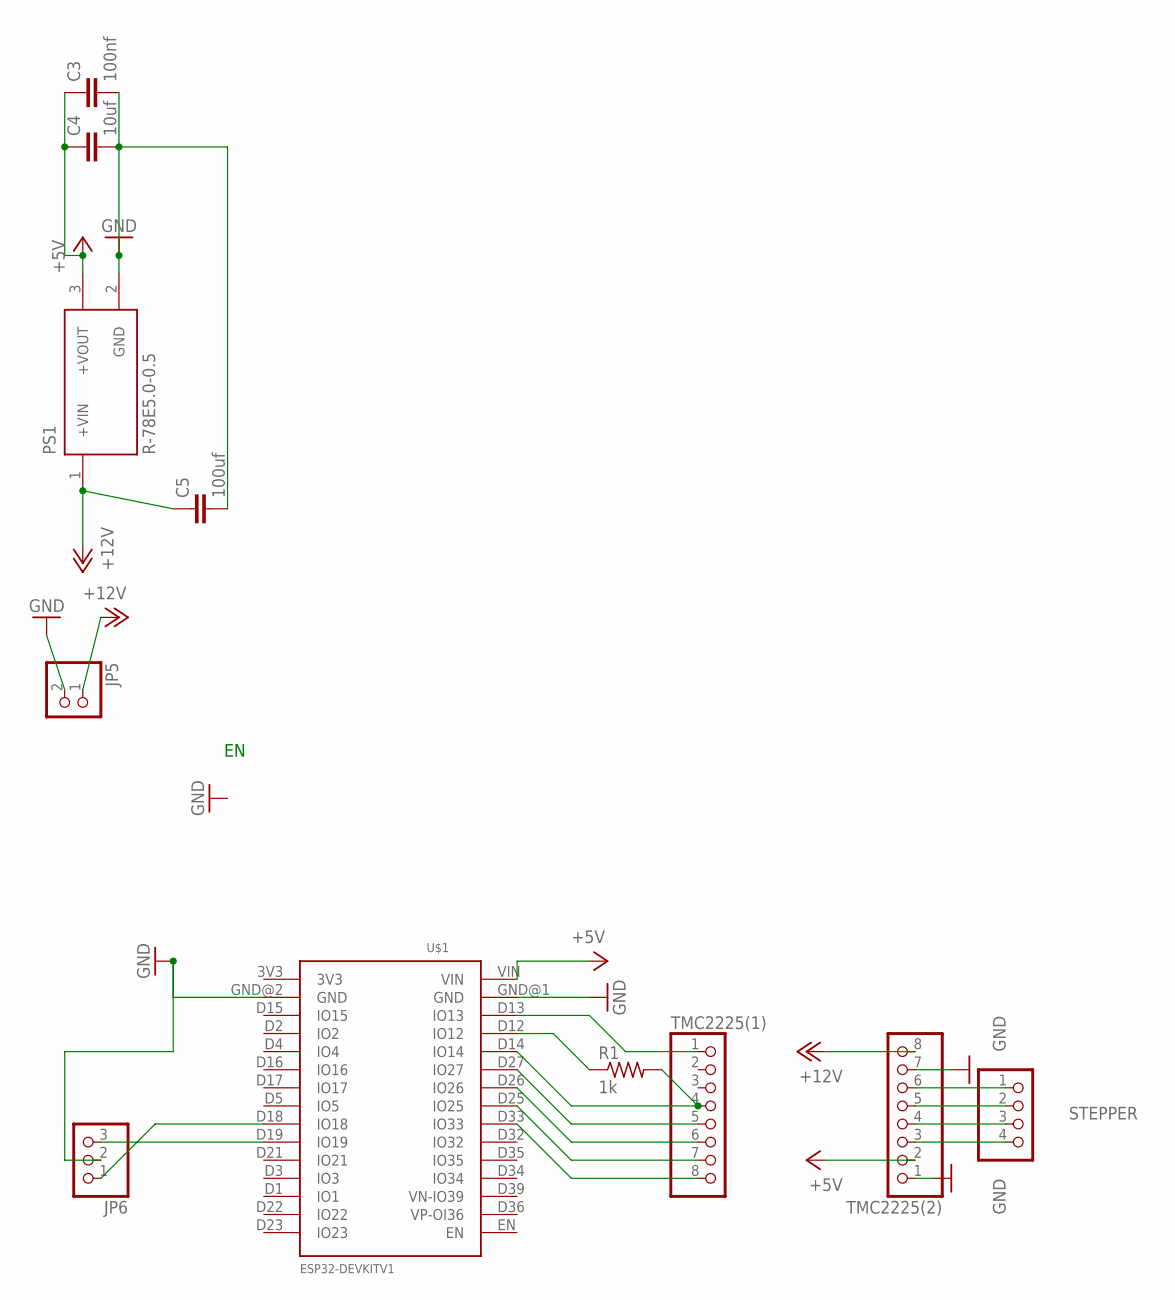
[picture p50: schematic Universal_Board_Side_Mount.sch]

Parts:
C3: 100nf; C2.5-3
C4: 10uf; C2.5-3
C5: 100uf; C2.5-3
JP5: PINHD-1X2; 1X02
JP6: PINHD-1X3; 1X03
PS1: R-78E5.0-0.5; CONV_R-78E5.0-0.5
R1: 1k; 0204/7
STEPPER: PINHD-1X4; 1X04
TMC2225(1), TMC2225(2): PINHD-1X8; 1X08
U$1: ESP32DEVKITV1; ESP32-DEVKITV1

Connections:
+5V: C3.1, C4.1, PS1.3 (+VOUT), TMC2225(2).2, U$1.VIN
+12V: C5.1, JP5.1, PS1.1 (+VIN), TMC2225(2).8
GND: C3.2, C4.2, C5.2, JP5.2, JP6.2, PS1.2 (GND), TMC2225(2).1, TMC2225(2).7, U$1.GND@1 (GND), U$1.GND@2 (GND)
unnamed: R1.2, TMC2225(1).4, U$1.D14 (IO14)
unnamed: TMC2225(1).1, U$1.D13 (IO13)
unnamed: R1.1, U$1.D12 (IO12)
unnamed: TMC2225(1).5, U$1.D27 (IO27)
unnamed: TMC2225(1).6, U$1.D26 (IO26)
unnamed: TMC2225(1).7, U$1.D25 (IO25)
unnamed: TMC2225(1).8, U$1.D33 (IO33)
unnamed: STEPPER.1, TMC2225(2).6
unnamed: STEPPER.2, TMC2225(2).5
unnamed: STEPPER.3, TMC2225(2).4
unnamed: STEPPER.4, TMC2225(2).3
unnamed: JP6.3, U$1.D19 (IO19)
unnamed: JP6.1, U$1.D18 (IO18)

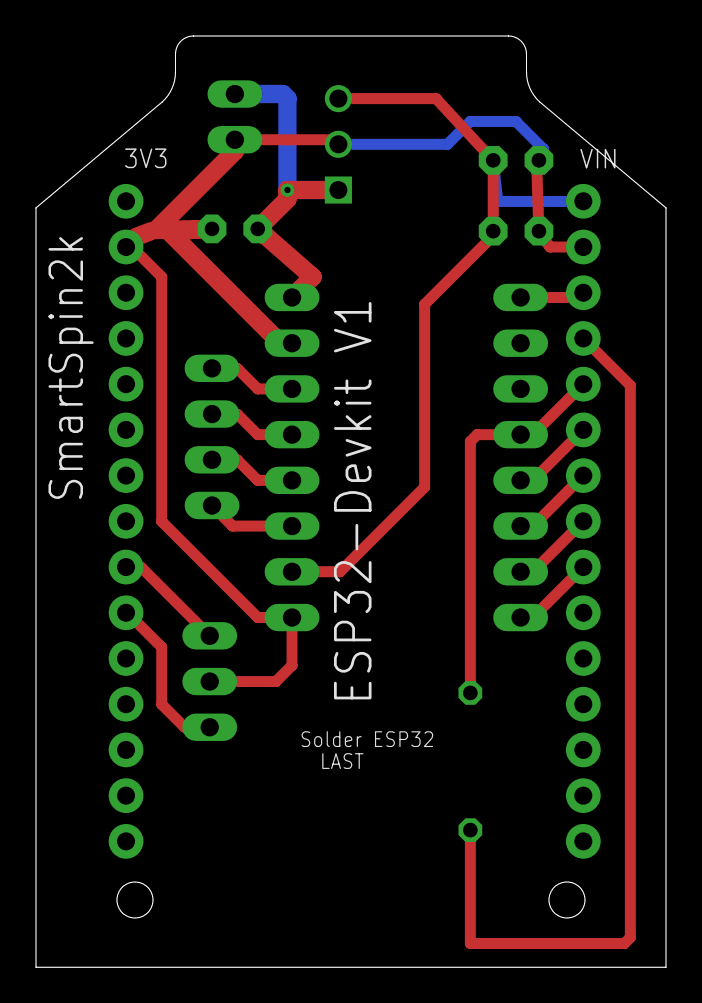
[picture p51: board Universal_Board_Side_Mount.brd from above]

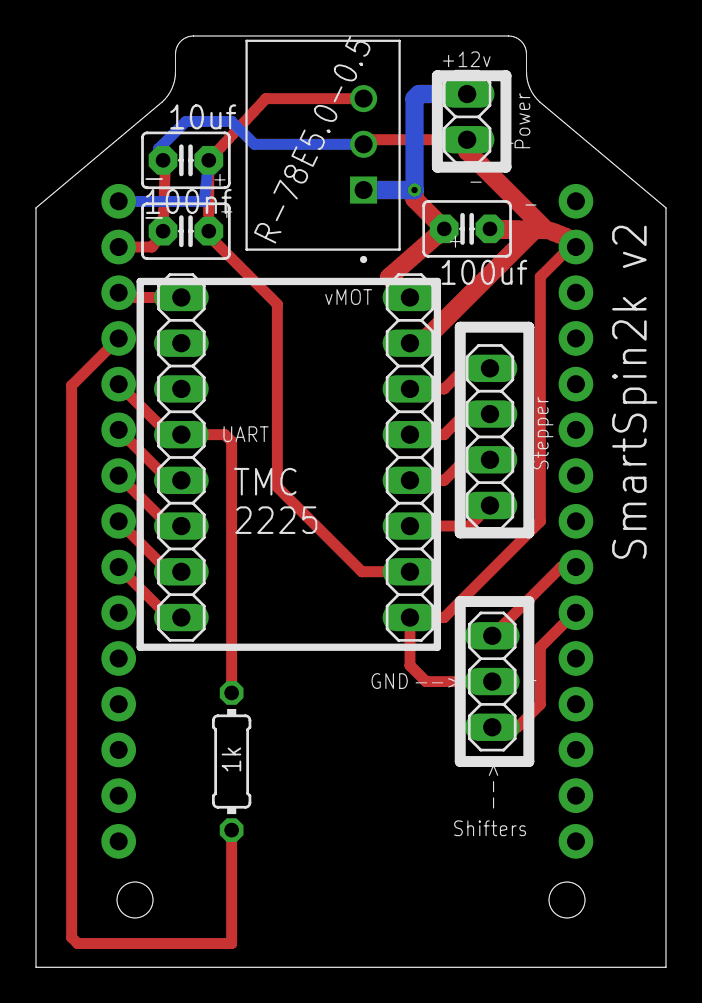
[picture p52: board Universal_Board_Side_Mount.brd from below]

Board: 2 copper layers, 35.0 x 51.7 mm, 11 parts (10 on the bottom side), 16 nets.

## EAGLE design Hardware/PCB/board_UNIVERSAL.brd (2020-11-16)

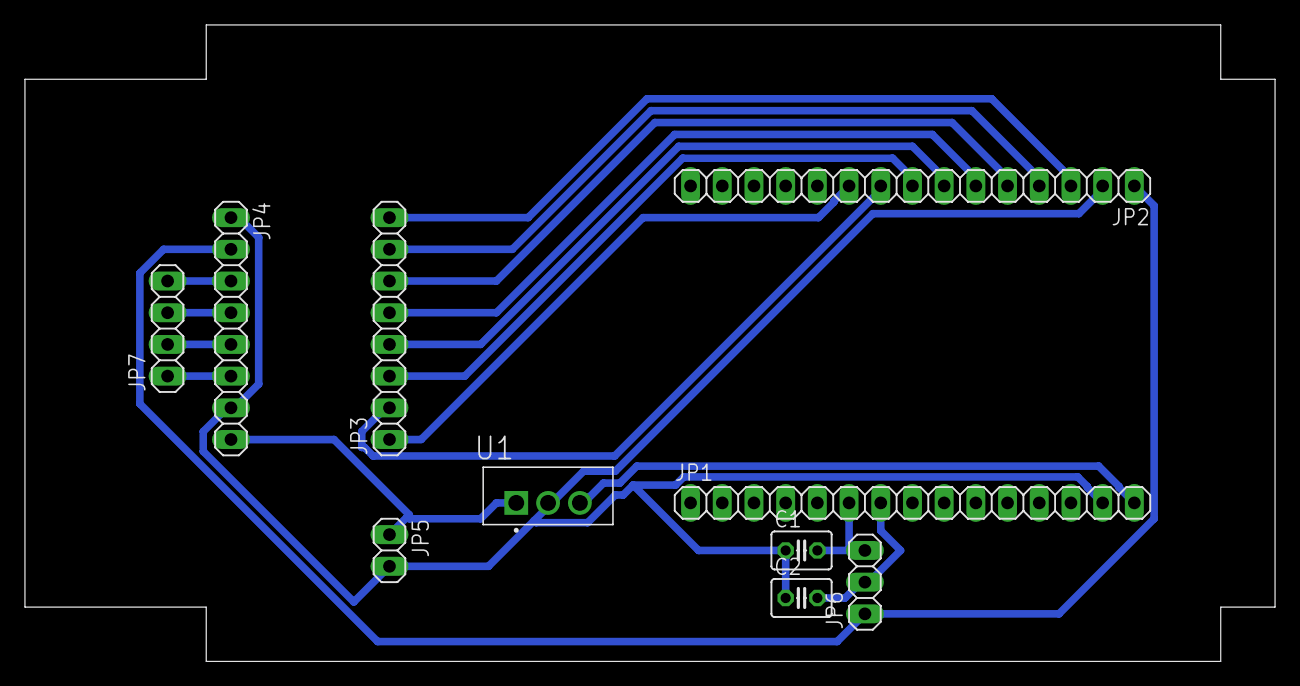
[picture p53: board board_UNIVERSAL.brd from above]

Board: 2 copper layers, 100.2 x 51.0 mm, 10 parts (0 on the bottom side), 18 nets.

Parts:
C1, C2: C025-030X050
JP1, JP2: 1X15
JP3, JP4: 1X08
JP5: 1X02
JP6: 1X03
JP7: 1X04
U1: L7805CV; TO255P1040X460X1968-3

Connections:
+3V3: JP2.1, JP4.2, JP6.1
+5V: JP1.15, U1.3
+12V: JP4.8, JP5.1, U1.1
GND: C1.1, C2.1, JP1.14, JP2.2, JP4.1, JP4.7, JP5.2, U1.2
unnamed: C2.2, JP1.7, JP6.2
unnamed: C1.2, JP1.6, JP6.3
unnamed: JP2.10, JP3.1
unnamed: JP2.8, JP3.3
unnamed: JP2.7, JP3.4
unnamed: JP2.6, JP3.5
unnamed: JP2.9, JP3.2
unnamed: JP4.6, JP7.1
unnamed: JP4.5, JP7.2
unnamed: JP4.4, JP7.3
unnamed: JP4.3, JP7.4
unnamed: JP2.5, JP3.6
unnamed: JP2.4, JP3.7
unnamed: JP2.3, JP3.8

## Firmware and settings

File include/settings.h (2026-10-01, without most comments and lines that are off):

#pragma once
const char* const DEVICE_NAME = "SmartSpin2k";
const char* const DEFAULT_PASSWORD = "password";
#define FW_UPDATEURL "https://raw.githubusercontent.com/doudar/OTAUpdates/main/"
#if defined(SMARTSPIN2K_S3)
#define FW_VERSIONFILE "S3version.txt"
#define FW_BINFILE     "S3firmware.bin"
#define FS_BINFILE     "S3littlefs.bin"
#else
#define FW_VERSIONFILE "version.txt"
#define FW_BINFILE     "firmware.bin"
#define FS_BINFILE     "littlefs.bin"
#endif
#if defined(SMARTSPIN2K_S3)
#define DATA_UPDATEURL "https://raw.githubusercontent.com/doudar/SmartSpin2k/develop/data_s3"
#else
#define DATA_UPDATEURL "https://raw.githubusercontent.com/doudar/SmartSpin2k/develop/data"
#endif
#define DATA_FILELIST "/list.json"
#define configFILENAME "/config.txt"
#define POWER_TABLE_FILENAME "/PowerTable.txt"
#define BUILD_VERSION_FILENAME "/build_version.txt"
#define INCLINE_MULTIPLIER 7.0f
#define MIN_PCF .5f
#define MAX_PCF 2.5f
#define DEFAULT_STEPPER_POWER 900
#define DEFAULT_SHIFT_STEP 1200
#define STEPPER_ACCELERATION 3000
#define DEFAULT_STEPPER_SPEED 3500
#define HOLD_PWR_SCALER .3f
#define PWR_SCALER_FOR_HOMING 0.8f
#define ERG_SENSITIVITY 3.0f
#define ERG_PER_SHIFT 10
#define FTMS_PASSTHROUGH false
#define MIN_ERG_CADENCE 20
#define DEFAULT_MIN_WATTS 50
#define DEFAULT_MAX_WATTS 1000
#define MIN_PELOTON_RESISTANCE 5
#define MAX_PELOTON_RESISTANCE 98
#define MIN_ECHELON_RESISTANCE 5
#define MAX_ECHELON_RESISTANCE 30
#define DEFAULT_RESISTANCE_RANGE 2000
#define DEFAULT_STEPPER_TRAVEL 200000000
#define DEBOUNCE_DELAY 200
#define BLE_NOTIFY_DELAY 503
#define BLE_CLIENT_DELAY 101
#define DIRCON_MANAGER_DELAY 20
#define AUX_SERIAL_DELAY 100
#define NUM_BLE_DEVICES 3
#define WEBSERVER_DELAY 12
constexpr const char* NONE = "none";
constexpr const char* ANY  = "any";
#define CONNECTED_POWER_METER NONE
#define CONNECTED_HEART_MONITOR NONE
#define CONNECTED_REMOTE NONE
#define STEALTHCHOP true
#define WIFI_CONNECT_TIMEOUT 10
#define BLE_CLIENT_DISCONNECT_TIMEOUT 5000
#define MAIN_MAINTENANCE_INTERVAL_MS 6007
#define RIDER_STATUS_LOG_INTERVAL_MS 1000
#define DEBUG_LOG_BUFFER_SIZE 600
#define ERG_MODE_USE_POWER_TABLE
#define ERG_MODE_USE_PID
#define ERG_MODE_PID_WINDOW 20
#define TABLE_VERSION 6
#define POWERTABLE_WATT_SIZE 30
#define POWERTABLE_CAD_SIZE 10
#define POWERTABLE_WATT_INCREMENT 30
#define MINIMUM_TABLE_CAD 60
#define POWERTABLE_CAD_INCREMENT 5
#define POWER_SAMPLES 3
#define MAX_NEIGHBOR_WEIGHT 20
#define POWER_TABLE_HISTORY         4
#define POWER_SAMPLE_MAX_AGE_MS     1500
#define POWER_SAMPLE_MIN_SPACING_MS 750
#define POWER_SAMPLE_SETTLE_MS      2000
#define POWER_SAMPLE_POSITION_SPAN  100
#define POWER_SAMPLE_CADENCE_SPAN   3
#define POWER_TABLE_SAVE_INTERVAL 240000
#define NORMAL_CAD 90
#define MINIMUM_RELIABLE_POSITIONS 3
#define TABLE_DIVISOR 10.0f
#define AUX_BUF_SIZE 10
#define PELOTON_TX true
#define TX_CHECK_INTERVAL 20
#define DEFAULT_HOMING_SENSITIVITY 50
#define HOME_TIMEOUT                  45000
#define HOMING_SG_SAMPLE_COUNT        24
#define HOMING_SG_MIN_SAMPLE_MARGIN   10
#define HOMING_SG_MAX_THRESHOLD_DRIFT 30
#define HOMING_TAP_MAX_ATTEMPTS       7
#define HOMING_TAP_REQUIRED_STABLE    3
#define HOMING_TAP_TOLERANCE          150
#define HOMING_RECOVERY_BACKOFF_MULT  3
#define HOMING_MAX_SENSITIVITY        100
#define SHIFTER_MIDDLE_POSITION       8
#define BLE_RECONNECT_SCAN_INTERVAL 8000
#define DEFAULT_SCAN_DURATION 5000
#if defined(SMARTSPIN2K_S3)
#define MAIN_STACK       8000
#define BLE_CLIENT_STACK 8000  // S3 has additional internal RAM and external QSPI PSRAM.
#else
#define MAIN_STACK       4500
#define BLE_CLIENT_STACK 6000  // Scans and connects to BLE devices. Holds the BLE Notify Data.
#endif

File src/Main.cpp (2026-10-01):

/*
 * Copyright (C) 2020  Anthony Doud & Joel Baranick
 * All rights reserved
 *
 * SPDX-License-Identifier: GPL-2.0-only
 */

#include "Main.h"
#include "Stepper.h"
#include "SS2KLog.h"
#include <Arduino.h>
#include "driver/gpio.h"
#include <cctype>
#include <cstdlib>
#include <LittleFS.h>
#include <HardwareSerial.h>
#include "ERG_Mode.h"
#include "Power_Table.h"
#include "UdpAppender.h"
#include "WebsocketAppender.h"
#include "BleAppender.h"
#include "BLE_Custom_Characteristic.h"
#include "BLE_Definitions.h"
#include <Constants.h>
#include "settings.h"
#include "BLE_Fitness_Machine_Service.h"
#include "BLE_OpenBikeControl_Service.h"
#include "DirConManager.h"
#include "ThermalSafety.h"

// Peloton Serial
HardwareSerial auxSerial(1);
AuxSerialBuffer auxSerialBuffer;

TaskHandle_t maintenanceLoopTask;

Boards boards;
Board currentBoard;

///////////// Initialize the Config /////////////
ErgMode* ergMode            = new ErgMode;
PowerTable* powerTable      = new PowerTable;
SS2K* ss2k                  = new SS2K;
userParameters* userConfig  = new userParameters;
RuntimeParameters* rtConfig = new RuntimeParameters;

#ifndef UNIT_TEST
namespace {
RTC_NOINIT_ATTR bool inhibitLedOnBoot = false;

#ifdef SERIAL_CUSTOM_CHARACTERISTIC
constexpr size_t SERIAL_CUSTOM_CHARACTERISTIC_MAX_REQUEST = 128;

// Debug-only USB serial protocol:
//   cc 01 1e              read BLE_stepperSpeed
//   cc 02 1e b8 0b 00 00  write BLE_stepperSpeed (3000, little-endian)
// Each complete command is newline-delimited and replies as `cc_response` followed
// by the characteristic's raw response bytes in hexadecimal.
void processSerialCustomCharacteristic() {
  static char line[SERIAL_CUSTOM_CHARACTERISTIC_MAX_REQUEST * 3 + 1];
  static size_t lineLength = 0;

  while (Serial.available()) {
    const int received = Serial.read();
    if (received < 0) return;

    if (received == '\r') continue;
    if (received == '\n') {
      line[lineLength] = '\0';

      if (lineLength >= 2 && line[0] == 'c' && line[1] == 'c') {
        uint8_t request[SERIAL_CUSTOM_CHARACTERISTIC_MAX_REQUEST];
        size_t requestLength = 0;
        char* cursor = line + 2;
        bool valid = true;

        while (*cursor != '\0') {
          while (*cursor == ' ' || *cursor == '\t') cursor++;
          if (*cursor == '\0') break;
          if (requestLength == sizeof(request) || !isxdigit(static_cast<unsigned char>(cursor[0])) || !isxdigit(static_cast<unsigned char>(cursor[1]))) {
            valid = false;
            break;
          }

          char byteText[] = {cursor[0], cursor[1], '\0'};
          request[requestLength++] = static_cast<uint8_t>(strtoul(byteText, nullptr, 16));
          cursor += 2;
          if (*cursor != '\0' && *cursor != ' ' && *cursor != '\t') {
            valid = false;
            break;
          }
        }

        if (valid && requestLength >= 2 && request[1] != BLE_allSettings) {
          BLE_ss2kCustomCharacteristic::process(std::string(reinterpret_cast<const char*>(request), requestLength), BLE_HS_CONN_HANDLE_NONE, 23, false);
          NimBLEService* service = NimBLEDevice::getServer()->getServiceByUUID(SMARTSPIN2K_SERVICE_UUID);
          NimBLECharacteristic* characteristic = service == nullptr ? nullptr : service->getCharacteristic(SMARTSPIN2K_CHARACTERISTIC_UUID);
          if (characteristic != nullptr) {
            NimBLEAttValue response = characteristic->getValue();
            Serial.print("cc_response");
            for (size_t i = 0; i < response.size(); ++i) {
              Serial.printf(" %02x", response[i]);
            }
            Serial.println();
          } else {
            Serial.println("cc_error unavailable");
          }
        } else {
          Serial.println("cc_error invalid_request");
        }
      }

      lineLength = 0;
      continue;
    }

    if (lineLength < sizeof(line) - 1) {
      line[lineLength++] = static_cast<char>(received);
    } else {
      lineLength = 0;
      Serial.println("cc_error request_too_long");
    }
  }
}
#endif

  // RTC memory survives commanded ESP.restart() calls but not power loss. A set
  // flag means the previous reboot was intentional, so consume it and keep the
  // LED quiet until activity turns it back on.
bool shouldStartWithLedEnabled() {
  bool inhibitLed = inhibitLedOnBoot;
  inhibitLedOnBoot = false;
  return !inhibitLed;
}

// Set a flag in RTC memory to keep the LED off on the next boot.
void keepLedOffAfterReboot() {
  inhibitLedOnBoot = true;
}
}  // namespace
#endif

///////////// Log Appender /////////////
UdpAppender udpAppender;
WebSocketAppender webSocketAppender;
BleAppender bleAppender;

///////////// BEGIN SETUP /////////////
#ifndef UNIT_TEST

void SS2K::startTasks() {
  SS2K_LOG(MAIN_LOG_TAG, "Start BLE + ERG Tasks");
  setupBLE();
}

void SS2K::stopTasks() {
  // In favor of stopping the tasks, BLE communications loop just disconnects all connected devices.
}

extern "C" void app_main() {
  initArduino();
  // Serial port for debugging purposes
  Serial.begin(115200);

  BaseType_t taskCreated = xTaskCreatePinnedToCore(SS2K::maintenanceLoop,     /* Task function. */
                                                   "maintenanceLoopFunction", /* name of task. */
                                                   MAIN_STACK,                /* Stack size of task */
                                                   NULL,                      /* parameter of the task */
                                                   10,                        /* priority of the task */
                                                   &maintenanceLoopTask,      /* task handle */
                                                   1);                        /* pin task to core */
  if (taskCreated != pdPASS) {
    Serial.println("Failed to create maintenance task; restarting");
    ESP.restart();
  }
}

void SS2K::finishSetup() {
  SS2K_LOG(MAIN_LOG_TAG, "Compiled %s%s", __DATE__, __TIME__);
#if defined(SMARTSPIN2K_S3)
  currentBoard = boards.rev3;
#else
  // Revisions one and two share the same hardware-detection pin.
  currentBoard = boards.rev1;
#endif
  pinMode(currentBoard.revisionPin, INPUT);
  int actualVoltage = analogRead(currentBoard.revisionPin);
#if defined(SMARTSPIN2K_S3)
  SS2K_LOG(MAIN_LOG_TAG, "Board ID ADC on GPIO%d: %d (expected %d +/- %d)", currentBoard.revisionPin, actualVoltage, currentBoard.versionVoltage,
           currentBoard.versionTolerance);
  if (abs(actualVoltage - currentBoard.versionVoltage) > currentBoard.versionTolerance) {
    SS2K_LOG(MAIN_LOG_TAG, "WARNING: Board ID resistor does not match the ESP32-S3 hardware revision");
  }
#else
  if (actualVoltage - boards.rev1.versionVoltage >= boards.rev2.versionVoltage - actualVoltage) {
    currentBoard = boards.rev2;
  } else {
    currentBoard = boards.rev1;
  }
#endif
  SS2K_LOG(MAIN_LOG_TAG, "Current Board Revision is: %s", currentBoard.name.c_str());
  // Disable before serial, filesystem or WiFi setup can delay current limiting.
  gpio_set_level(static_cast<gpio_num_t>(currentBoard.enablePin), 1);
  pinMode(currentBoard.enablePin, OUTPUT);
  digitalWrite(currentBoard.enablePin, HIGH);

  // initialize Stepper serial port

  initializeStepperSerial();
  // initialize aux serial port (Peloton)
  if (currentBoard.auxSerialTxPin) {
    auxSerial.begin(19200, SERIAL_8N1, currentBoard.auxSerialRxPin, currentBoard.auxSerialTxPin, false);
    if (!auxSerial) {
      SS2K_LOG(MAIN_LOG_TAG, "Invalid Serial Pin Configuration");
    }
    auxSerial.onReceive(SS2K::rxSerial, true);  // setup callback
  }
  // Initialize LittleFS
  SS2K_LOG(MAIN_LOG_TAG, "Mounting Filesystem");
  if (!LittleFS.begin(false)) {
    SS2K_LOG(MAIN_LOG_TAG, "An Error has occurred while mounting LittleFS.");
    LittleFS.format();  // Format so that the settings can be saved.
    delay(100);         // Provide some time for the format to happen.
  }

  // Load Config
  userConfig->loadFromLittleFS();
  ss2k->resetStartingGear();
  userConfig->printFile();  // Print userConfig->contents to serial
  userConfig->saveToLittleFS();

  // if we have homing data, use that instead.
  if (userConfig->getHMax() != INT32_MIN && userConfig->getHMin() != INT32_MIN) {
    SS2K_LOG(MAIN_LOG_TAG, "Using homing data from config file.");
    spinBLEServer.spinDownFlag = 1;
  }

  // print littleFS free space and all file sizes on partition
  Serial.printf("LittleFS Total Bytes:%lu, Used Bytes:%lu\n", LittleFS.totalBytes(), LittleFS.usedBytes());
#if defined(SMARTSPIN2K_S3)
  SS2K_LOG(MAIN_LOG_TAG, "S3 heap: %u bytes, PSRAM: %u bytes", ESP.getHeapSize(), ESP.getPsramSize());
  if (!psramFound()) {
    SS2K_LOG(MAIN_LOG_TAG, "WARNING: ESP32-S3 QSPI PSRAM was not detected");
  }
#endif

  // Start WiFi early, then let the maintenance loop finish network setup.
  startWifi();
  httpServer.syncWebServerFiles();

  pinMode(currentBoard.shiftUpPin, INPUT_PULLUP);    // Push-Button with input Pullup
  pinMode(currentBoard.shiftDownPin, INPUT_PULLUP);  // Push-Button with input Pullup
  pinMode(currentBoard.ledPin, OUTPUT);
  pinMode(currentBoard.enablePin, OUTPUT);
  pinMode(currentBoard.dirPin, OUTPUT);   // Stepper Direction Pin
  pinMode(currentBoard.stepPin, OUTPUT);  // Stepper Step Pin
  digitalWrite(currentBoard.enablePin,
               HIGH);  // Should be called a disable Pin - High Disables FETs
  digitalWrite(currentBoard.dirPin, LOW);
  digitalWrite(currentBoard.stepPin, LOW);
  digitalWrite(currentBoard.ledPin, LOW);
  ss2k->setLEDEnabled(shouldStartWithLedEnabled());

  ss2k->setupTMCStepperDriver();
  // Assign the power-on knob position to the starting gear without moving it.
  // Homing, when configured, replaces this provisional coordinate later.
  if (stepper) {
    ss2k->setTargetPosition(ss2k->gearTargetPosition(rtConfig->getShifterPosition()));
    stepper->setCurrentPosition(ss2k->getTargetPosition());
    ss2k->setCurrentPosition(stepper->getCurrentPosition());
  }
  ss2k->updateHardwareSafety();  // Establish thermal limits before BLE can start homing.

  SS2K_LOG(MAIN_LOG_TAG, "Setting up cpu Tasks");

  // disableCore0WDT();  // Disable the watchdog timer on core 0 (so long stepper
  //  moves don't cause problems)

  digitalWrite(currentBoard.ledPin, LOW);
  // Configure and Initialize Logger
  logHandler.addAppender(&webSocketAppender);
  logHandler.addAppender(&udpAppender);
  logHandler.addAppender(&bleAppender);
  logHandler.initialize();
  ss2k->startTasks();
  httpServer.start();
  updateWifi();

#ifdef TEST_PTAB4PWR
  userConfig->setHMin(0);
  userConfig->setHMax(27000);
  rtConfig->setMaxStep(userConfig->getHMax());
  rtConfig->setMinStep(userConfig->getHMin());
  rtConfig->setHomed(true);
  userConfig->setPTab4Pwr(true);
  spinBLEServer.spinDownFlag = 0;
#endif

  ss2k->resetIfShiftersHeld();
  digitalWrite(currentBoard.ledPin, LOW);
}

void loop() {  // Delete this task so we can make one that's more memory efficient.
  vTaskDelete(NULL);
}

void SS2K::maintenanceLoop(void*) {
  finishSetup();

  static unsigned long maintenanceTimer    = millis();
  static unsigned long riderStatusLogTimer = millis();
  static unsigned long rebootTimer         = millis();
  static uint32_t hardwareSafetyTimer      = millis();

  while (true) {
    delay(10);
    updateWifi();
    // Keep thermal protection active during updates; the check defers during homing.
    if (uint32_t(millis() - hardwareSafetyTimer) >= ThermalSafety::POLL_INTERVAL_MS) {
      hardwareSafetyTimer = millis();
      ss2k->updateHardwareSafety();
    }
    BLEFirmwareUpdateLoop();
    ss2k->syncFtmsPosition();

#ifdef SERIAL_CUSTOM_CHARACTERISTIC
    processSerialCustomCharacteristic();
#endif

    // be quiet while updating via BLE
    if (!ss2k->isUpdating) {
      // Drain deferred BLE settings callbacks before shift/motor processing,
      // without waiting for the periodic telemetry timer or using nimble_host.
      ss2kCustomCharacteristic.processPendingEvents();
      static unsigned long bleTimer = millis();
      // 500ms
      if ((millis() - bleTimer) > BLE_NOTIFY_DELAY) {
        BLECommunications();
        logHandler.writeLogs();
        webSocketAppender.Loop();
        bleTimer = millis();
      }
      // Don't do these if updating and in spindown mode.
      if (!spinBLEServer.spinDownFlag) {
        // Clamp/interpret a shift before it can command motor movement.
        ss2k->FTMSModeShiftModifier();
        ss2k->moveStepper();
        ergMode->runERG();
      }

      // if this hardware version has serial pins, check and process their data.
      // only do this every AUX_SERIAL_DELAY
      static unsigned long auxSerialTimer = millis();
      if ((millis() - auxSerialTimer) > AUX_SERIAL_DELAY) {
        if (currentBoard.auxSerialTxPin) {
          ss2k->txSerial();
        }
        auxSerialTimer = millis();
      }
    }

    // Handle the shifters
    ss2k->handleShiftButtons();

    // send BLE notification for any userConfig values that changed.
    BLE_ss2kCustomCharacteristic::parseNemit();
    httpServer.webClientUpdate();
    // Update DirCon protocol
    DirConManager::update();
    ss2k->updateLED();
    // If we're in ERG mode, modify shift commands to inc/dec the target watts instead.

    // If we have a resistance bike attached, slow down when we're close to the limits.
    if (stepper && ss2k->pelotonIsConnected && !rtConfig->getHomed() && !spinBLEServer.spinDownFlag) {
      int speed           = userConfig->getStepperSpeed();
      float resistance    = rtConfig->resistance.getValue();
      float maxResistance = rtConfig->getMaxResistance();

      // Slow down when resistance is within 20% of the lower limit
      if (resistance < (maxResistance * 0.2)) {
        float factor = resistance / (maxResistance * 0.2);
        speed        = static_cast<int>(factor * userConfig->getStepperSpeed());
        if (speed < 500) {
          speed = 500;
        }
        if (ss2k->targetPosition > stepper->getCurrentPosition()) {
          speed = userConfig->getStepperSpeed();
        }
      }

      // Slow down when resistance is within 20% of the upper limit
      if (resistance > (maxResistance * 0.8)) {
        float factor = (maxResistance - resistance) / (maxResistance * 0.2);
        speed        = static_cast<int>(factor * userConfig->getStepperSpeed());
        if (speed < 500) {
          speed = 500;
        }
        if (ss2k->targetPosition < stepper->getCurrentPosition()) {
          speed = userConfig->getStepperSpeed();
        }
      }
      ss2k->updateStepperSpeed(speed);
    }

    // Handle flag set for rebooting
    if (ss2k->rebootFlag) {
      static bool _loopOnce = false;
      delay(1000);
      // Let the main task loop complete once before rebooting
      if (_loopOnce) {
        // Important to keep this delay high in order to allow coms to finish.
        delay(1000);
        ESP.restart();
      }
      _loopOnce = true;
    }

    // Handle a flag set to reset SmartSpin2k to defaults
    if (ss2k->resetDefaultsFlag) {
      LittleFS.format();
      userConfig->setDefaults();
      powerTable->reset();
      userConfig->saveToLittleFS();
      ss2k->resetDefaultsFlag = false;
      ss2k->rebootFlag        = true;
    }

    // required to set a flag instead of directly calling the function for saving from BLE_Custom Characteristic.
    if (ss2k->saveFlag) {
      ss2k->saveFlag = false;
      userConfig->saveToLittleFS();
    }

    // Periodic maintenance.
    if ((millis() - maintenanceTimer) > MAIN_MAINTENANCE_INTERVAL_MS) {
      // Reboot after half an hour without meaningful pedaling. Also treat unchanged values as inactive because disconnected servers can leave stale readings behind.
      constexpr int inactivityThreshold             = 10;
      constexpr unsigned long inactivityRebootDelay = 1800000;
      static int oldHR                              = 0;
      static int oldWatts                           = 0;
      static int oldCadence                         = 0;
      static float oldTargetIncline                 = 0.0f;
      bool powerAndCadenceAreLow = rtConfig->watts.getValue() < inactivityThreshold && rtConfig->cad.getValue() < inactivityThreshold;
      bool readingsAreUnchanged = oldHR == rtConfig->hr.getValue() && oldWatts == rtConfig->watts.getValue() && oldCadence == rtConfig->cad.getValue() &&
                                  oldTargetIncline == rtConfig->getTargetIncline();
      bool riderIsInactive      = powerAndCadenceAreLow || readingsAreUnchanged;
      if (riderIsInactive) {
        if ((millis() - rebootTimer) > inactivityRebootDelay) {
          // Timer expired
          SS2K_LOG(MAIN_LOG_TAG, "Rebooting due to inactivity.");
          keepLedOffAfterReboot();
          ss2k->rebootFlag = true;
          logHandler.writeLogs();
          webSocketAppender.Loop();
        }
      } else {
        // Fresh active readings restart the full inactivity window.
        oldHR            = rtConfig->hr.getValue();
        oldWatts         = rtConfig->watts.getValue();
        oldCadence       = rtConfig->cad.getValue();
        oldTargetIncline = rtConfig->getTargetIncline();
        rebootTimer      = millis();
        ss2k->setLEDEnabled(true);
      }

#ifdef DEBUG_STACK
      if (!ss2k->isUpdating) {
        SS2K_LOG(MAIN_LOG_TAG, "Maintenance Task: %d", uxTaskGetStackHighWaterMark(maintenanceLoopTask));
        SS2K_LOG(MAIN_LOG_TAG, "BLEClient: %d", uxTaskGetStackHighWaterMark(BLEClientTask));
        SS2K_LOG(MAIN_LOG_TAG, "Min Heap: %d", esp_get_minimum_free_heap_size());
        SS2K_LOG(MAIN_LOG_TAG, "Free Heap: %d", esp_get_free_heap_size());
        SS2K_LOG(MAIN_LOG_TAG, "Best Block: %d", heap_caps_get_largest_free_block(MALLOC_CAP_8BIT));
      }
#endif  // DEBUG_STACK
      // Connection state changes infrequently, so keep it out of the one-second rider status record.
      SS2K_LOG(MAIN_LOG_TAG, "DEV PM=%d CAD=%d HRM=%d", spinBLEClient.connectedPM, spinBLEClient.connectedCD, spinBLEClient.connectedHRM);
      maintenanceTimer = millis();
    }

    if ((millis() - riderStatusLogTimer) >= RIDER_STATUS_LOG_INTERVAL_MS) {
      // Log rider status for diagnostics and ride analysis.
      SS2K_LOG(MAIN_LOG_TAG, "W=%d C=%d H=%d G=%d R=%d P=%d->%d", rtConfig->watts.getValue(), rtConfig->cad.getValue(), rtConfig->hr.getValue(),
               rtConfig->getShifterPosition(), rtConfig->resistance.getValue(), ss2k->getCurrentPosition(), ss2k->getTargetPosition());

      riderStatusLogTimer = millis();
    }
  }
}

#endif  // UNIT_TEST

void SS2K::setLEDEnabled(bool enabled) {
  ledEnabled = enabled;
  if (!enabled) {
    digitalWrite(currentBoard.ledPin, LOW);
  }
}

void SS2K::updateLED() {
  if (!ledEnabled) {
    digitalWrite(currentBoard.ledPin, LOW);
    return;
  }

  int currentCount = spinBLEServer.connectedClientCount();
  if (currentCount == 0) {
    // No app/client connected yet: simple idle blink.
    digitalWrite(currentBoard.ledPin, (millis() / 500) % 2 == 0 ? LOW : HIGH);
    return;
  }

  // Connected: stay mostly on, then count clients as brief off-pulses.
  constexpr unsigned long pulseOffTime = 200;
  constexpr unsigned long pulseGap     = 300;
  constexpr unsigned long countGap     = 5000;
  unsigned long pulsePeriod            = pulseOffTime + pulseGap;
  unsigned long cycleDuration          = currentCount * pulsePeriod + countGap;
  unsigned long cyclePosition           = millis() % cycleDuration;

  // After the diagnostic pulses, return to solid-on connected status.
  if (cyclePosition >= currentCount * pulsePeriod) {
    digitalWrite(currentBoard.ledPin, HIGH);
    return;
  }

  // Each pulse starts with a short off dip, followed by on-time between dips.
  digitalWrite(currentBoard.ledPin, (cyclePosition % pulsePeriod) < pulseOffTime ? LOW : HIGH);
}
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

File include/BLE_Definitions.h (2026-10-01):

/*
 * Copyright (C) 2020  Anthony Doud & Joel Baranick
 * All rights reserved
 *
 * SPDX-License-Identifier: GPL-2.0-only
 */

#pragma once

#include <array>
#include <cstdint>
#include "ByteUtils.h"

// The .xml file is wrong, make sure to reference the actual FTMS .pdf
struct FitnessMachineIndoorBikeDataFlags {
  enum Types : uint16_t {
    MoreDataBit                 = 1U << 0,
    AverageSpeedPresent         = 1U << 1,
    InstantaneousCadencePresent = 1U << 2,
    AverageCadencePresent       = 1U << 3,
    TotalDistancePresent        = 1U << 4,
    ResistanceLevelPresent      = 1U << 5,
    InstantaneousPowerPresent   = 1U << 6,
    AveragePowerPresent         = 1U << 7,
    ExpendedEnergyPresent       = 1U << 8,
    HeartRatePresent            = 1U << 9,
    MetabolicEquivalentPresent  = 1U << 10,
    ElapsedTimePresent          = 1U << 11,
    RemainingTimePresent        = 1U << 12
  };
};

inline FitnessMachineIndoorBikeDataFlags::Types operator|(FitnessMachineIndoorBikeDataFlags::Types a, FitnessMachineIndoorBikeDataFlags::Types b) {
  return static_cast<FitnessMachineIndoorBikeDataFlags::Types>(static_cast<int>(a) | static_cast<int>(b));
}

// https://www.bluetooth.com/specifications/specs/fitness-machine-service-1-0/
// Table 4.13: Training Status Field Definition
struct FitnessMachineTrainingStatus {
  enum Types : uint8_t {
    Other                           = 0x00,
    Idle                            = 0x01,
    WarmingUp                       = 0x02,
    LowIntensityInterval            = 0x03,
    HighIntensityInterval           = 0x04,
    RecoveryInterval                = 0x05,
    Isometric                       = 0x06,
    HeartRateControl                = 0x07,
    FitnessTest                     = 0x08,
    SpeedOutsideOfControlRegionLow  = 0x09,
    SpeedOutsideOfControlRegionHigh = 0x0A,
    CoolDown                        = 0x0B,
    WattControl                     = 0x0C,
    ManualMode                      = 0x0D,
    PreWorkout                      = 0x0E,
    PostWorkout                     = 0x0F,
    // Reserved for Future Use 0x10-0xFF
  };
};

// https://www.bluetooth.com/specifications/specs/fitness-machine-service-1-0/
// Table 4.24: Fitness Machine Control Point characteristic – Result Codes
struct FitnessMachineControlPointResultCode {
  enum Types : uint8_t {
    ReservedForFutureUse = 0x00,
    Success              = 0x01,
    OpCodeNotSupported   = 0x02,
    InvalidParameter     = 0x03,
    OperationFailed      = 0x04,
    ControlNotPermitted  = 0x05,
    // Reserved for Future Use = 0x06-0xFF
  };
};

// https://www.bluetooth.com/specifications/specs/fitness-machine-service-1-0/
// Table 4.3: Definition of the bits of the Fitness Machine Features field
struct FitnessMachineFeatureFlags {
  enum Types : uint32_t {
    AverageSpeedSupported              = 1U << 0,
    CadenceSupported                   = 1U << 1,
    TotalDistanceSupported             = 1U << 2,
    InclinationSupported               = 1U << 3,
    ElevationGainSupported             = 1U << 4,
    PaceSupported                      = 1U << 5,
    StepCountSupported                 = 1U << 6,
    ResistanceLevelSupported           = 1U << 7,
    StrideCountSupported               = 1U << 8,
    ExpendedEnergySupported            = 1U << 9,
    HeartRateMeasurementSupported      = 1U << 10,
    MetabolicEquivalentSupported       = 1U << 11,
    ElapsedTimeSupported               = 1U << 12,
    RemainingTimeSupported             = 1U << 13,
    PowerMeasurementSupported          = 1U << 14,
    ForceOnBeltAndPowerOutputSupported = 1U << 15,
    UserDataRetentionSupported         = 1U << 16
  };
};
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

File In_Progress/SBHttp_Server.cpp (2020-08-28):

/* Async Webpage server */

#include <SBHttp_Server.h>
//#include <HTTP_Server_Basic.h>
#include <smartbike_parameters.h>
#include <Main.h>

// Import required libraries
#include <Arduino.h>
#include <WiFi.h>
#include <WiFiAP.h>
#include <ESPAsyncWebServer.h>
#include <AsyncTCP.h>
#include <SPIFFS.h>
#include <FS.h>
#include <string.h>
#define MAX_BUFFER_SIZE 20

// Set LED GPIO
const int ledPin = 2; //Blue LED on the ESP32
// Stores LED state
String ledState;
// Webpage Parameter varables
const char* webStringParameter = "state";
const char* webIntParameter = "value";
int i; //Multi use integer for general purpose

/********************Added Function for SPIFFS File Testing*****************************/
void printFile(String filename) {
  // Open file for reading
  Serial.printf("Contents of file: %s/n", filename.c_str());
  File file = SPIFFS.open(filename);
  if (!file) {
    Serial.println(F("Failed to read file"));
    return;
  }

  // Extract each characters by one by one
  while (file.available()) {
    Serial.print((char)file.read());
  }
  Serial.println();

  // Close the file
  file.close();
}

/***************************************************************************************/
// Create AsyncWebServer object on port 80
AsyncWebServer server(80);

// Replaces placeholder with LED state value
String processor(const String& var){
  char outString[MAX_BUFFER_SIZE];
  Serial.printf("Processing Variable from HTTP Server: %s \n", var.c_str());
  
  if(var == "STATE"){
    if(digitalRead(ledPin)){
      ledState = "ON";
    }
    else{
      ledState = "OFF";
    }
    Serial.printf("LED State is %s \n", ledState.c_str());
    return ledState;
  }

  if(var =="HROUTPUT"){ 
      if(config.getSimulateHr()){return "checked";}
      else{return "";}
  }

    if(var =="WATTSOUTPUT"){ 
      if(config.getSimulatePower()){return "checked";}
      else{return "";}
  }

  if(var =="HRVALUE"){
  snprintf(outString, MAX_BUFFER_SIZE, "%d", config.getSimulatedHr());
  strncat(outString, " BPM", 4);
  //Serial.printf("outString: %s \n", outString);
  return outString;
  }

  if(var =="WATTSVALUE"){ 
  snprintf(outString, MAX_BUFFER_SIZE, "%d", config.getSimulatedWatts());
  strncat(outString, " Watts", 6);
  return outString;
  }
  
  return String();
}

void startHttpServer(){

  pinMode(ledPin, OUTPUT);

  // Connect to Wi-Fi
  Serial.println();
  Serial.println("Configuring access point...");
  WiFi.softAP(config.getSsid(), config.getPassword());
  vTaskDelay(50);
  IPAddress myIP = WiFi.softAPIP();
  Serial.print("AP IP address: ");
  Serial.println(myIP);
  server.begin();
  Serial.println("WiFi Server started");

  // Route for root / web page
  /* I think we need to expand this one server instance to keep from crashing instead of using multiple server.on instances */
  server.on("/", HTTP_GET, [](AsyncWebServerRequest *request){
    //request->send(SPIFFS, "/index.html", "text/html");
    request->send(SPIFFS, "/index.html", String(), true, processor);
    //request->
    //request->send(SPIFFS, "/style.css", "text/css");
    Serial.println("Index.html Sent");
    //printFile("/index.html");
  });
  
  // hopefully we can eventually delete all of this below
  // Route to load style.css file
  server.on("/style.css", HTTP_GET, [](AsyncWebServerRequest *request){
    request->send(SPIFFS, "/style.css", "text/css");
    Serial.println("/style.css Sent");
    printFile("/style.css");
  });
  // Route to set GPIO to HIGH
  server.on("/on", HTTP_GET, [](AsyncWebServerRequest *request){
    digitalWrite(ledPin, HIGH);    
    request->send(SPIFFS, "/index.html", String(), true, processor);
  });
  
  // Route to set GPIO to LOW
  server.on("/off", HTTP_GET, [](AsyncWebServerRequest *request){
    digitalWrite(ledPin, LOW);    
    request->send(SPIFFS, "/index.html", String(), true, processor);
  });

  //***************************************Trying to get a value from a range slider
  server.on("/hrslider", HTTP_GET, [] (AsyncWebServerRequest *request) {
        // GET input1 value on <ESP_IP>/hrslider?value=<inputMessage>
    String inputMessage;
    if (request->hasParam(webIntParameter)) {
      inputMessage = request->getParam(webIntParameter)->value();
      config.setSimulatedHr(inputMessage.toInt());
      Serial.printf("Heart Rate in Config is %d\n", config.getSimulatedHr());
    }
    else {
      inputMessage = "No message sent";
    }
    Serial.println(inputMessage);
    request->send(SPIFFS, "/index.html", String(), true, processor);
    //request->send(200, "text/plain", "OK");
  });
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

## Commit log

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2022-01-02 possible QZ fix #1
    [Main.cpp]
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2022-01-04 Added ultra short case mod
    [3.5mmJack.SLDASM, 54-00063-1.SLDPRT, 54-00063-3.SLDPRT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]
2022-01-05 UI changes (#295)
    * Added confirm dialog by settings reset and file mask for firmware upload
    * reformated settings.html
    * Show the name of all html files requested
    * moved form submit to click event handler
    * removed http request logging for index
    * Changed Title for cache debugging
    * added confirmation overlay
    * enabled refresh
    * added css to upload extensions
    * update changelog
    * added css for reset buttons
2022-01-05 Removed secondary indicate when a shift was preformed with the BLE custom characteristic. (#300)
    * possible QZ fix #1
    * fixed definition
    * Update CHANGELOG.md
    [Main.cpp]
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2022-01-30 Reworked logging. Implemented Appender Pattern. Added WebSockets Logger
    [Main.cpp, Main.h]
2022-02-05 Fixed bug in external_control
    [Main.cpp]
2022-02-05 rework of ic4 paths, re-drawn arm and bike mounts, readme revisions
    [Direct Mount Case v2.f3z, Direct Mount Case v2.step, Echelon Connect Sport.stl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]
2022-02-06 Workaround to connect HRM first
    [Main.cpp]
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2022-07-09 Over Temp Loggin Fix
    [Main.cpp]
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2022-07-09 Fixed returns above POWERTABLE_SIZE
    [settings.h]
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2022-08-21 minor case adjustments
    motor mount has much tighter tolerances
    Should be a bit easier to insert the screw for the Arm
    [Direct Mount Mod v6.f3z, Direct Mount Mod v6.step, body-left.stl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]
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2022-09-05 direct mount improvements
    tolerance improvements on case
    added files for peloton
    [Direct Mount Case v2.f3z, Direct Mount Case v2.step, Direct Mount Mod v11.step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]
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2022-09-22 short case tweak
    tweak to short case - screw posts needed a chamfer at the body wall to improve printability.
    [Body_Drawing_Right.STEP, Body_Drawing_Right.STL.stl]
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2022-09-30 Ultra short direct mount for Bowflex C7 and others
    Ultra short case mod and Bowflex C7 direct mount
    [Bowflex C7.f3d, Bowflex C7.step, Bowflex C7.stl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]
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2022-10-14 SS2K Uploaded PCB Revision 2.2
    Removed unnecessary files and replaced the new KiCad SS2K files with the most recent revision (2.2)
    [BOM-SmartSpin2k.csv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]
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2022-10-18 beefier arm
    should be less prone to cracking if tolerances are tight
    [_arm hook.stl, schwinn ic4.stl]
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2022-10-19 beefier arm
    Slightly thicker to reduce risk of cracking in case of tight printer tolerances
    [_arm hook.stl, schwinn ic4.stl]
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2022-10-21 Lots of stuff
    Bolt through option for ultra short case - enables direct mount on bikes with a square profile head tube
    beefier arms for all direct mount options
    Life Fitness IC7 direct mount
    [Body_Drawing_Left_Bolt_Arm.3MF, Body_Drawing_Left_Bolt_Arm.STL, Echelon Connect Sport.stl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]
2022-10-21 Delete Peloton_60mm.STL
    no longer needed
    [Peloton_60mm.STL]
2022-10-21 short case direct mount
    [Body-Right.stl, body-left.stl]
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2022-10-21 Revert "Delete Peloton_7_flat v2.stl"
    This reverts commit c8bf1ebde589ecc256d5b043f7c89f5a4fe326f6.
    [Peloton_7_flat v2.stl]
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2022-10-31 added txCheck interval preventing uart spamming
    [Main.cpp, Main.h, settings.h]
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2022-11-29 Echelon update
    Flat surface on the echelon insert too thin and prone to tear. Thickened to 1mm
    [Echelon_60mm.SLDPRT, Echelon_60mm.STL, Echelon_60mm.step]
2022-11-29 Revert "Echelon update"
    This reverts commit 16b28afbdf412940a95ad5bf3474c85172914a22.
    [Echelon_60mm.SLDPRT, Echelon_60mm.STL, Echelon_60mm.step]
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2022-12-05 Fixed Transistor Footprint, Added new Switch, Chamfered corners
    [JS102011SAQN.step, SmartSpin2k.kicad_pcb, SmartSpin2k.kicad_sch]
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2022-12-07 added reboot when BLE device selection changed
    [Main.cpp, SmartSpin_parameters.h]
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2022-12-15 Fixed: Window Chamfer, Switch hole, reinforced Window opening.
    [Body_Drawing.SLDPRT, Body_Drawing_Left.SLDPRT, Body_Drawing_Right.SLDPRT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]
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2022-12-25 added check if devices are connected. Min ERG fix
    Added a check to stop automatic scanning if both devices are connected.
    Fixed bug submitted by @flo100 where MIN_WATTS in ERG should have been userConfig.getMinWatts();
    [Main.cpp]
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2023-01-04 fixed resistance mode limiting
    [Main.cpp]
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2023-01-08 fixed "none" and "none" scanning
    [Main.cpp]
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2023-01-11 Fix to stop oscillating on min resistance.
    Changed < and > to <= and >= in line 273 and 274 below so it doesn't switch when it is already on min or max resistance.
    [Main.cpp]
2023-01-11 fixed greater than sign
    [Main.cpp]
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2023-01-19 Fixed Component rotations
    [CPL-SmartSpin2k.csv, SmartSpin2k-CuBottom.gbr, SmartSpin2k-CuTop.gbr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]
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2023-01-23 Fixed bug where "none" hr still scanned
    [Main.cpp]
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2023-02-01 added Building Instructions. Added Fixed arms.
    [Arm_60_For_Assembly_Only.SLDPRT, Arm_70_For_Assembly_Only.SLDPRT, Bottom_Half.SLDASM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]
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2023-02-08 Fixed logic in ignoring power
    [SensorCollector.cpp]
2023-02-08 fixed saving logging setting
    [SmartSpin_parameters.cpp]
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2023-02-24 FIxed BLE_reconnect and no battery crash
    [settings.h]
2023-02-25 Still show a short line when BLE Debug turned off
    [SensorCollector.cpp]
2023-02-25 fixed Scanning with "none" selected
    [SmartSpin_parameters.cpp, SmartSpin_parameters.h, settings.h]
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2023-05-29 moving echelon insert to correct path
    [Echelon_60mm.STL]
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2023-08-09 updated arms
    added roundness, increased bolt hole tolerance to 5.05mm from 5mm. Still expect a tight fit but should be easier for a screw to self-tap into it. Keeping it snug to avoid floppy arm.
    [SS2K_Arm.scad, armWithHook100.STL, armWithHook105.STL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]
2023-08-09 Fixed Typo in pdf
    Changed reference to M4 bolt to M5 Bolt.
    Increased right side case mounting hole to 5.5mm so the bolt slides in easier.
    [Body_Drawing_Right.SLDPRT, Body_Drawing_Right.STEP, Body_Right.STL]
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2023-12-03 Increased delay after obtaining lookup value (trust the lookup value)
    Increased delay after obtaining lookup value (trust the lookup value) and wait for power to stabilize before running ERG again.
    [ERG_Mode.h]
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2023-12-05 Reworked_Schwinn_IC4 knob.
    Reworked_Schwinn_IC4 knob.
    [Schwinn_IC4.SLDPRT, Schwinn_IC4.STL, Schwinn_IC4_48.5mm.SLDPRT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]
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2023-12-10 fixed saving/loading table and fixed TorqueTable out of bounds bug.
    [ERG_Mode.h]
2023-12-11 Peloton 4a workaround until I can import the resistance table for Peloton.
    [Main.cpp, SensorCollector.cpp]
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2023-12-29 corrected file locations.
    [Yesoul S3 v6.step, Yesoul S3.stl]
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2024-01-24 reverted stack size settings
    [Main.cpp, settings.h]
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2024-02-07 Added inactivity reboot timer
    [Main.cpp, settings.h]
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2024-03-05 more reconnect stability improvements
    [settings.h]
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2024-03-09 moved inactivity reboot so that the log message from it gets delivered
    [Main.cpp]
2024-03-09 connect by address fixed
    [Main.cpp]
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2024-03-15 Scanned devices are no longer saved to the filesystem to prevent snowballing.
    [SmartSpin_parameters.cpp]
2024-03-16 Added a workaround for WiFi not working after fw upgrade
    [CPPLINT.cfg]
2024-03-16 Moved Reset to defaults into a flag
    [Main.cpp, Main.h]
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2024-03-17 - Added more robust activity monitoring and reboot every 30 minutes if there is no activity.
    [Main.cpp]
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2025-02-19 HRM data now updates correctly from multiple sensors
    [BLE_Fitness_Machine_Service.cpp, SensorCollector.cpp, settings.h]
2025-02-19 added horiz and vert range and constraint for moving failed neighbor with readings
    [settings.h]
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2025-02-22 changed failed neighbor constrain WIP
    [settings.h]
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2025-03-27 shifter position resets to 0 after homing
    [Main.cpp]
2025-03-28 shorter time before registering zero
    [settings.h]
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2025-05-04 fixed bug in testNeighbors()
    [settings.h]
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2025-05-27 fixed BLE with Zwift (BLE values were not being set, only Notified)
    [BLE_Fitness_Machine_Service.cpp]
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2025-05-31 fixed Rouvy connection issue
    [BLE_Fitness_Machine_Service.cpp]
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2025-06-25 Fix structure and cmake files to build with esp-idf
    [BLE_Fitness_Machine_Service.cpp, Main.cpp, SensorCollector.cpp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]
2025-06-25 Revert "Fix structure and cmake files to build with esp-idf"
    [BLE_Fitness_Machine_Service.cpp, Main.cpp, SensorCollector.cpp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]
2025-06-26 Revert "Changes from @h2zero"
    This reverts commit ecc4d225ebd9f764005461badf018643aa1ff964.
    [BLE_Fitness_Machine_Service.cpp, Main.cpp, SensorCollector.cpp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]
2025-07-02 fixed reboot on firmware update page load. Fixed BLE connections being slow to initiate
    [BLE_Fitness_Machine_Service.cpp, Main.cpp, SensorCollector.cpp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]
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2025-07-17 added timeout to homing. Fixed bug with hmin and hmax not being set over ble
    [Main.cpp]
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2025-07-29 Homing communication with client fixed
    [BLE_Definitions.h, BLE_Fitness_Machine_Service.cpp, Main.cpp]
2025-07-31 Improves power table handling and homing
    Improves power table loading by preventing reload attempts and explicitly setting hMin to zero for saved tables.
    Also, initiates a homing sequence when pTab4Pwr is enabled.
2025-07-31 - Fixed edge cases of pTab4Pwr causing runaways.
    [SmartSpin_parameters.h, settings.h]
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2025-08-07 debounce rework - faster shifting
    [Main.cpp, Main.h, settings.h]
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2025-08-17 bugfix for rare crash while scanning
    [settings.h]
2025-09-08 BLE client: Stable unique names for private random addresses
    Detect private random addresses via top bits (00/40).
    For these, suffix with last byte of manufacturer data if present; else base name.
    Keep legacy "Name xx" suffix for public/static addresses.
    Avoids Android address rotation breaking saved device selection.
2025-09-10 added NVS check in addition to config file. This is belt + suspenders, and i don't absolutely love that, but I really want to avoid a potential boot loop if littlefs gets corrupted.
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2025-09-16 Removed 5 minute battery update to test fix for tempo power meter.
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2025-09-22 removed client checking for "rebooting due to inactivity."
    [Main.cpp]
2025-09-22 automatic reboot fixes. Improved scan reliability.
    [Main.cpp]
2025-09-30 Fixed incline mode handling negative numbers.
    [BLE_Fitness_Machine_Service.cpp]
2025-10-19 BLE advertisement data reworked and optimized.
    [BLE_Fitness_Machine_Service.cpp]
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2025-11-03 Logging fixes and data length fixes
    [settings.h]
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2025-11-24 Add power scalers for stepper hold and homing; update driver settings for improved stall detection
    [Main.cpp, Main.h, settings.h]
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2025-12-17 Fix for Zwift On Android.
    [BLE_Fitness_Machine_Service.cpp]
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2026-01-19 Fix ERG mode logic and improve power table validation; reset target incline on stop
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2026-01-23 Add Sole SB1200 reference photos and update assets
    Added new reference photos for the Sole SB1200 bike in the Inserts/Design_Reference_Photos directory. Updated and replaced various reference images to reduce image sizes.
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2026-04-05 Update CA certificate for raw.githubusercontent.com
    - Replaced the outdated Sectigo certificate with the new Let's Encrypt R12 certificate.
    - Updated the last modified date to 2026-04-05.
    [Schwinn AC Star Knob.stp]
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2026-05-02 fix(ble): restructure advertising and ensure spec compliance for Garmin compatibility
    - Restructured BLE advertising to prioritize the Cycling Power Service (CPS) UUID (0x1818) in the primary packet, mimicking commercial power meters to bypass strict Garmin discovery filters.
    - Added BLE Appearance (0x0484) to explicitly identify the device as a Cycling Power Sensor.
    - Moved the SmartSpin2k custom service UUID to the scan response to prevent advertising packet overflow and reduce noise for central scanners.
    - Updated the Cycling Power Measurement characteristic to NOTIFY only to comply with the Bluetooth CPP v1.1 specification.
    - Forced a public MAC address type to ensure stable pairing with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
2026-05-02 fixed stepper dir regression
    [Stepper.cpp]
2026-05-22 sleep after 15min of inactivity after reboot
    [Main.cpp]
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2026-08-10 Enhance inactivity detection logic to reboot after 30 minutes without meaningful pedaling
    [Main.cpp]
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2026-08-14 Enhance TMC2209 connection recovery logic with interface counter validation and improve logging for UART test failures
    [Stepper.cpp]
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2026-08-20 Fix ERG latching off when cadence drops below 30
    [BLE_Fitness_Machine_Service.cpp, ERG_Mode.h]
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2026-08-24 PT Lookup Complete rework
    [SmartSpin_parameters.h, boards.h]
2026-08-26 Remove obsolete power table data files and add new tests for power table functionality
    - Deleted outdated power table files: power_table.ptab and power_table_incomplete.ptab.
    - Introduced new test file test_active_ride_table.cpp to validate ride log processing and power table generation.
    - Added test file test_power_table_csv.cpp to ensure correct saving and loading of power table data.
2026-08-26 Refactor power table tests for improved clarity and functionality
    - Consolidated test cases in `test_power_table_csv.cpp` to focus on active ride CSV round-trip validation.
    - Updated `test_pt_lookup_resistance.cpp` to enhance cadence boundary checks and active ride forward lookup tests.
    - Streamlined `test_pt_lookup_watts.cpp` by removing redundant output and focusing on active ride reverse lookup validation.
    - Removed unnecessary file output in `test_unity.cpp` and organized test execution for better readability.
    - Added checks for monotonicity in lookup functions and ensured proper handling of edge cases in power table lookups.
    [ERG_Mode.h, ERG_Mode_Utils.h]
2026-08-27 Safer BLE custom char parsing and serial debug
    Improve robustness and add a debug serial hook. Changes: replace byte-conversion macros with well-typed static_cast versions (include/BLE_Common.h); update root CA cert and timestamp (include/cert.h); enable SERIAL_CUSTOM_CHARACTERISTIC in debug build (platformio.ini) and add sdkconfig.S3debug; harden BLE custom characteristic parsing with required-length checks, safe integer assembly, bounds fix, and use setTarget for watts (src/BLE_Custom_Characteristic.cpp); add a newline-delimited serial command interface to invoke the custom characteristic for debugging (src/Main.cpp).
    [Main.cpp]
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2026-08-30 Fix classic ESP32 OTA memory use and remove boot updates
    - stream browser firmware uploads through the ESP-IDF OTA API
    - avoid Arduino Update's 4 KiB heap allocation
    - remove automatic boot-time firmware installation
    - retain boot-time web filesystem refresh and missing-file repair
    - deprecate the automatic-update setting while preserving compatibility
    - regenerate classic and S3 settings assets
    [Main.cpp, SmartSpin_parameters.cpp, SmartSpin_parameters.h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]
2026-08-30 Enhance filesystem upload handling and stepper initialization safety
    - Implement independent initialization of FastAccelStepper for safe operation without TMC UART.
    - Improve filesystem upload process with detailed error handling and remounting logic.
    - Ensure stepper-related functions check for initialization status to prevent runtime errors.
    [Main.cpp, Stepper.cpp]
2026-08-30 Refactor BLE and HTTP server functionalities; update cert updater script
    - Updated cert_updater.py to clarify its usage and removed direct execution in PlatformIO builds.
    - Added refreshBLEAdvertisementIp() function to BLE_Server for IP address updates in advertisements.
    - Modified syncWebServerFiles() in HTTP_Server to improve filesystem repair logic and error handling.
    - Enhanced DirConManager to check for active clients before broadcasting notifications.
    - Refactored startWifi() to streamline network service management and improve connection handling.
    - Improved error logging and handling across various components for better debugging and reliability.
    [Main.cpp]
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2026-09-05 fixes to address 0 brake watts
    [Main.cpp, SmartSpin_parameters.cpp]
2026-09-08 Tooling updates
    - Switch CI to pioarduino Core 6.1.19 with isolated caches.
    - Correct classic ESP32 flash size to 4 MB while retaining S3’s 16 MB.
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2026-09-18 Fix phantom shift aborting homing
    resetStartingGear() wrote rtConfig shifterPosition without updating
    lastShifterPosition. At boot, finishSetup() calls it and a configured
    groupset returns a nonzero start gear (count/3), so the two values
    disagree immediately.
    When saved homing data exists, spinDownFlag is set at boot and the
    maintenance loop skips FTMSModeShiftModifier(), so nothing ever
    reconciles that delta. The first homing attempt then sees
    shifterPosition != lastShifterPosition on its first loop iteration and
    aborts via the rider-shift check, failing on tap 1 after only backing
    off the end stop.
    Sync the baseline in resetStartingGear(), since a programmatic gear
    reset is not a rider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
    [Stepper.cpp]
2026-09-18 Block Unlimited gearing shifts past the travel limits
    The local-gearing branch in FTMSModeShiftModifier() returns before the
    sim-mode shift blocking. clampGear() bounds a configured groupset, but
    Unlimited has no gear ceiling, so the gear counter kept climbing while
    simulationTargetPosition() saturated at the travel limit. The rider then
    had to shift back through the dead gears before the knob moved.
    Check the projected travel target for Unlimited and revert the shifter
    position when it would cross a limit, matching the legacy path. The
    unclamped target calculation moves to gearTargetPosition() so the check
    and the motor path cannot disagree.
    Also ignore .clangd, which is local tooling con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
    [Main.cpp, Main.h]
2026-09-19 Updated the firmware to match the companion app’s calibration parser: - Live resistance gauge updates. - Correct minimum → maximum progress. - Saved range and completion messages. - Recognized abort 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
    [BLE_Fitness_Machine_Service.cpp, FtmsHoming.h, HardwareSafety.cpp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]
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2026-09-19 FTMS homing and drift compensation
    [FtmsCalibration.h, FtmsHoming.h, Main.cpp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]
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2026-09-21 Refactor Virtual Gearing Logic and Enhance FTMS Homing Tests
    - Updated SS2K::resetStartingGear to incorporate homingFallback logic for gear selection.
    - Introduced activeGearRatios method to streamline gear ratio retrieval based on homing state.
    - Modified localGearingSelected and gearTargetPosition methods to utilize activeGearRatios.
    - Enhanced FTMS homing tests to account for new gear logic and added scenarios for mechanical failures.
    - Improved test coverage for power table management and calibration processes.
    - Added a new test for BLE log streaming to ensure live logs do not replay after suppressed notifications.
    [BLE_Fitness_Machine_Service.cpp, FtmsCalibration.h, FtmsHoming.h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]
2026-09-24 Fixed WiFi not connecting bug.
    [Main.cpp]
2026-09-26 When not homed, gear 8 is starting position. Fixes knob moving up 8 shifts after start.
    [Main.cpp]
2026-09-27 Fix custom characteristic callbacks on fast maintenance loop
    [Main.cpp]
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2026-09-27 Refactor ERG mode settings and constants into ERG_Mode_Settings.h; update references in ERG_Mode.h and ERG_Mode_Utils.h -Changed ERG Small Error Gain to .50
    [ERG_Mode.h, ERG_Mode_Settings.h, ERG_Mode_Utils.h]
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2026-10-01 Require two consecutive reports before an ERG table feedback correction
    A single power report beyond ERG_TABLE_CORRECTION_WATTS (44 W) is usually a
    pedaling disturbance (standing, shifting position) that has passed by the
    next report. Rides on 2026-09-29 and 2026-10-01 showed one-report spikes
    (129 W and 119 W at a 68 W target) firing 1000-1350 step table corrections
    that left power 20-25 W under target for about 8 seconds.
    The previous fresh report must now also exceed the limit in the same
    direction. Correction sizing still uses the current report; sizing from the
    smaller error slowed sustained-disturbance recovery past 15 s at a 3 s meter
    delay. Adds the pedal_spike scenario to test_erg_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
    [ERG_Mode.h, ERG_Mode_Settings.h]
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2026-10-07 Bound ERG cadence compensation and ignore 1 RPM cadence jitter
    - Trusted-seek cadence following and proportional cadence compensation
    ignore changes under ERG_CADENCE_FOLLOW_DEADBAND_RPM (2) from their
    reference. Sub-deadband changes accumulate, including across power
    feedback moves, so slow drift is still compensated.
    - Proportional compensation applies at most
    ERG_CADENCE_COMPENSATION_MAX_RPM (3) per update and logs each move;
    power feedback corrects any remainder. A surge caused by the previous
    resistance drop can no longer remove ~1000 steps at once, unlogged.
    - test_erg_feedback: cadence_surge covers jitter, the cap and drift
    accumulation; seek_deadline jitter widened to 9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
2026-10-10 Peloton power/cadence now publish immediately, preserving packet validation and freshness fixes. Ordinary ERG corrections run at most every 700 ms, using the latest reading. Trend braking now works w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
2026-10-10 Derive power-table collection test spans from settings constants
    170664b3 widened POWER_SAMPLE_POSITION_SPAN (100 -> 250) and
    POWER_SAMPLE_CADENCE_SPAN (3 -> 5), but the cadence and
    cumulative_small_moves scenarios hardcoded the old limits, failing
    native-tests on all platforms. The scenarios now step just beyond the
    configured spans, so they keep testing the reset behaviour whatever the
    values are. AGENTS.md now names the constants and their current values.
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2026-10-12 Add packet-integrated ride performance tests and behavioral regressions
    Run real CPS/CSC bytes through production notification, queue, collector and sensor parsing; use production FTMS control packets with a virtual motor and independent bike plant. Pin develop comparisons, record sensor/plant metrics separately, retain provisional failures and verify a stuck-motor negative control. Preserve safety/protocol tests and replace brittle resistance/UI assertions.
    No production firmware source changes.
2026-10-12 Synchronize bench stream test and test exact PR head
    Replace a scheduler-dependent 5 ms sleep with explicit received-frame/EOF synchronization so Windows validates the same counter behavior. Check out the PR head explicitly in ride-performance evidence instead of the synthetic merge ref.
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2026-10-13 Document paired high-power ERG validation and remaining regressions
    Include all-case metrics, raw-signal plots, fixed reproduction inputs, separate source/test/build identities, and preserved budget failures. No private ride inputs or firmware binaries are included.
    180 paired cases completed. Universal stable +/-10 W under ten seconds remains unmet; hardware validation is required.
2026-10-13 Fix configurable power-table collection diagnostics
    Print the configured position gate and actual pending travel or collection span.
    Keep the 250-step gate and acquisition behavior unchanged. Exercise boundary,
    negative-direction, reconfigured-limit and extreme-coordinate logging paths.
2026-11-02 ERG: hold steady-state knob on stepped-resistance bikes (Peloton Bike+ via Grupetto)
    The Bike+ brake moves in whole 1% levels (5-8 W at 160-220 W). Small
    proportional corrections crept the knob until it crossed a level and
    overshot, then reversed (repeated level flips within one steady interval
    on real Bike+ rides). With fresh Grupetto resistance feedback, after a
    transition settles, hold the knob within +/-4 W, correct 4-10 W errors
    only after 1.5 s on one side, and correct >=10 W immediately. Bikes
    without resistance feedback are unchanged: the default simulator run
    (Random_Attacks, FTP 305) is byte-identical to develop.
    Simulator: optional resistance_step_steps/resistance_hysteresis_step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

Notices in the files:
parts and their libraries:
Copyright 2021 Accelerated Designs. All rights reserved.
